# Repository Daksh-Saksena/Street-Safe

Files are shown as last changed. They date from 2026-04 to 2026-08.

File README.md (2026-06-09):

# StreetSafe:
Disaster-response system designed to help people navigate safely during heavy rain and flooding. It improves on traditional GPS by using real-time data to guide users away from unsafe roads. Also the MAIN thing- An autonomous drone that can monitor conditions on the ground, update routes, and assist in search and rescue when situations become bad

So there are 2 parts of our Project, the physical design and drone , and the front end code base:-

___

# DRONE:
We designed the entire custom model including electronics (and 2 custom PCBS) in fusion and kicad, and made a wiring diagram including all the components and the wiring.
## What differentiates us?
Due to our goal of a helpful autonomous weatherproof drone, we had to add multiple unique differentiating parts-

1. Weatherproofing and waterproofing while maintaining airflow to cool components
2. Constant Lidar sensing on top of the drone to autonomously navigate
3. Payload mechanisms which can easilt be swapped out, For a start we have designed two mechanisms already:

* First Aid and small package deliverer - We designed a payload dropper mechanism to drop first aid boxes in times of flooded rains

* WIFI booster - In tree surrounded areas wifi connectivity gets worse exponentially so our drone acts as a network booster such that people can connect to internet and can call in case of emergencies.

___

# CODE:
This codebase is split into two main parts:
1. A Raspberry Pi 5 control system that is designed to run on actual hardware -> WARNING! ! ! -> WE DONT HAVE THE PHSYICAL COMPONENTS YET SO THIS IS LIKE A PLACEHOLDER!
2. A simulation (for testing and demoing) and dashboard system that runs in the browser and backend

Both parts implement the same core idea: an autonomous system that moves toward a goal or keep patrol while continuously avoiding obstacles and adapting to its environment.
1. Raspberry Pi (real-world system)
The pi module contains the code intended to run on a Raspberry Pi connected to a drone.
This part of the code:
* Connects to a flight controller using MAVLink
* Reads data from sensors such as LiDAR and distance sensors
* Processes that data to detect obstacles and measure distances
* Runs a control loop that decides how the drone should move
* Sends movement commandsback to the FC

In each cycle, the system:
1. Reads sensor data
2. Determines if the path ahead is clear
3. Adjusts direction if obstacles are detected
4. Continues moving toward the goal
This is the execution layer that would control a real drone.

2. Simulator + Dashboard (testing system)
The backend and frontend modules together act as a simulation environment.
This 
* Simulates the drone’s position and movement on a map
* Allows obstacles and walls to be placed interactively
* Runs the same navigation logic used on the Pi
* Displays everything visually in real time
It handles
* Routing between locations
* Flood-aware path calculation
* System state updates

The frontend:
* Displays the map (Leaflet)
* Shows the drone, its path, and obstacles
* Updates continuously as the system runs

Key ideas:--
* Move toward a goal or post etc.
* Detect obstacles
* Adjust direction dynamically
* Continue until the destination is reached
The simulator is used for testing and visualisaion (looks v cool) , while the Raspberry Pi code is designed to run the same logic on real hardware or atleast i think it will work .

## How to use:
To run: 
In bash
cd ........./streetsafe
./run_demo.sh

Then open:
http://localhost:9000

This starts the backend and launches dashboard where you can see- drone moving, place obstacles, and test navigation.

___

## Why did we do this? 
where we live-> bangalore gets heavy rains all the time (even in the summer) and its really bad traffic on top of the already infamous bangalore traffic but this can also get quite deadly, so we started this originally as a hackathon project (just some code which is now sitting in Old-website) but then we realised that this could actually be a fun and usefull project and here we are!

Note: Shipping prices are high even on the cheapest project, due to customs while shipping to where we live (India). We have selected the cheapest options.

___

## 3D MODEL
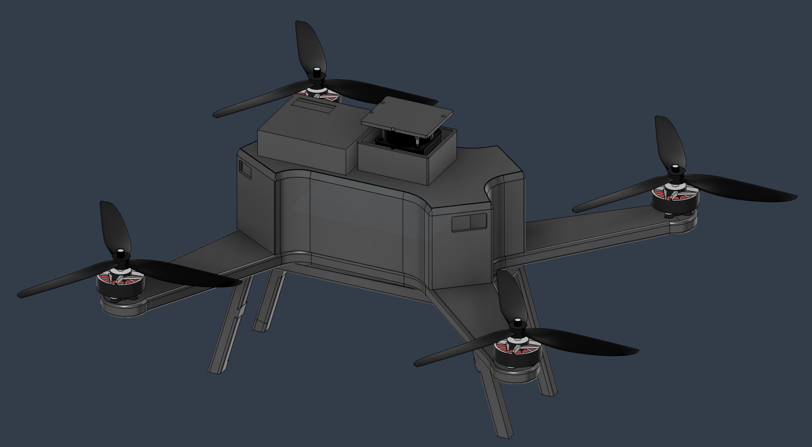
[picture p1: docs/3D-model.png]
3D model


___

## WIRING DIAGRAM
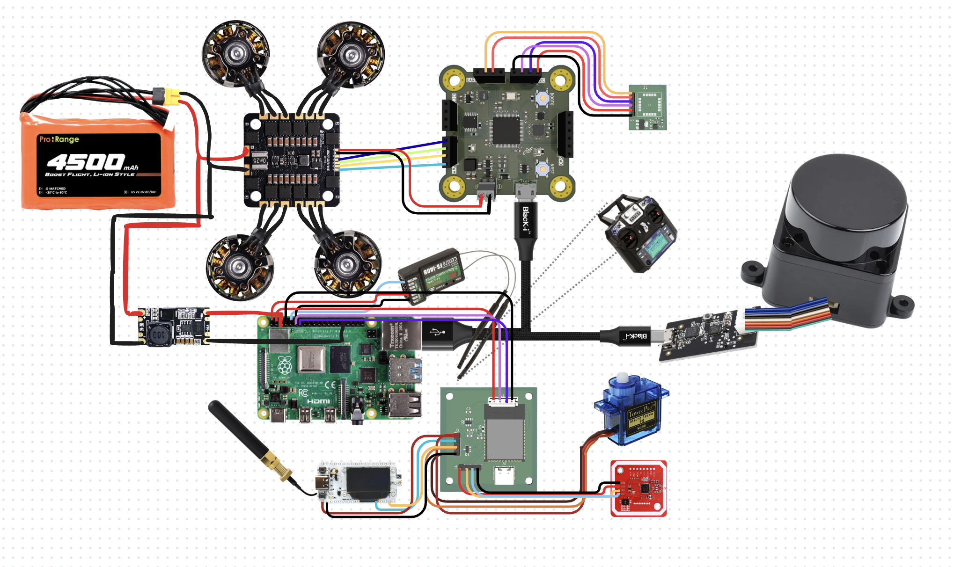
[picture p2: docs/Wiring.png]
Wiring


___

## 3D MODEL OF ELECTRONICS
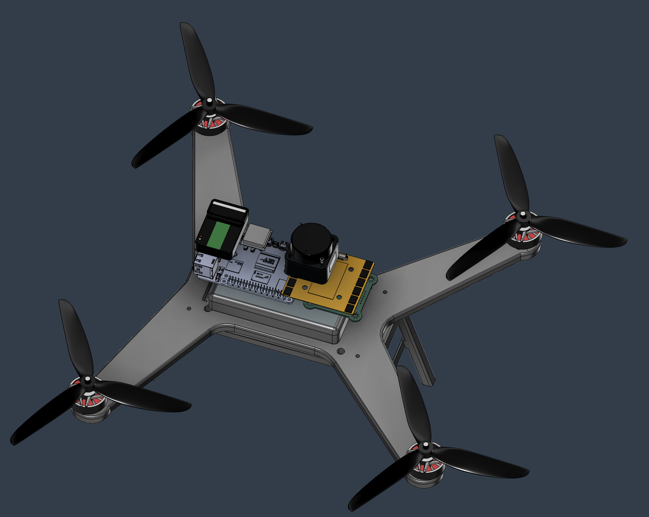
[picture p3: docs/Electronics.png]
Electronic


___

## PAYLOAD 1 - WiFi
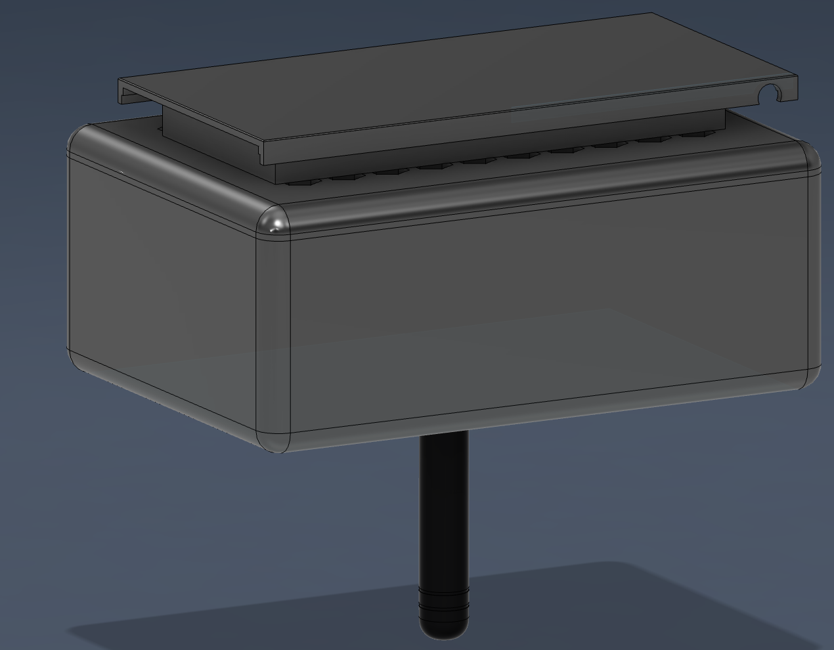
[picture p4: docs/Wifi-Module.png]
Wifi


___

## PAYLOAD 2 - Dropping
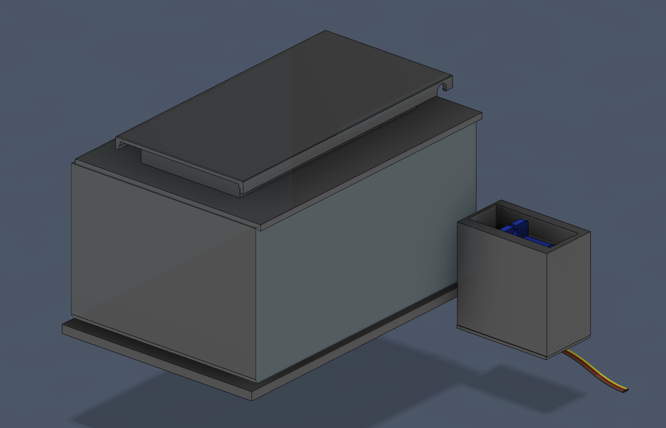
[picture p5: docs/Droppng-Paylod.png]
Dropping payload


___

## PCB 1,2 and 3: FC, GPS and PAYLOAD
<p align="center">
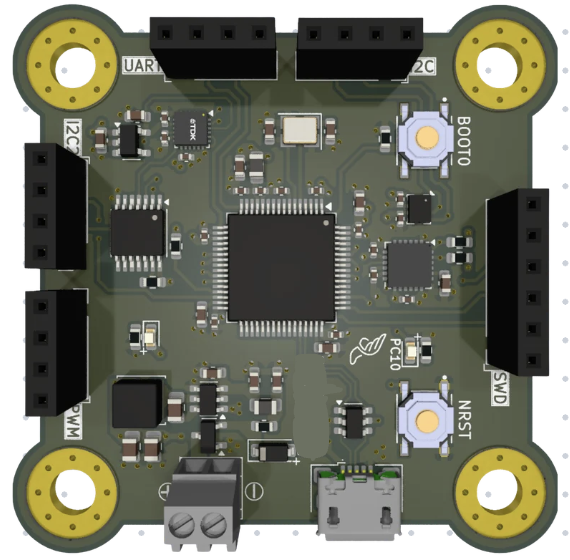
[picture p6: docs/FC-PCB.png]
FC
  
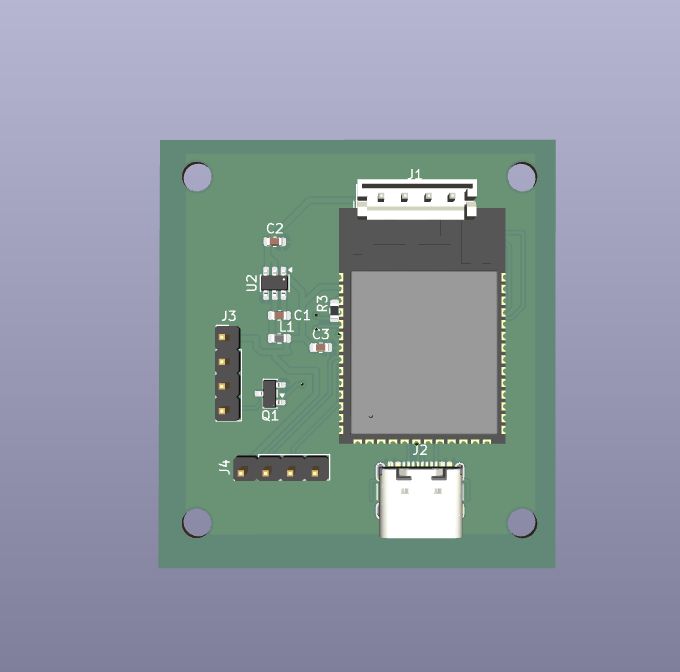
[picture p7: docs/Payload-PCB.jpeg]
PAYLOAD PCB
  
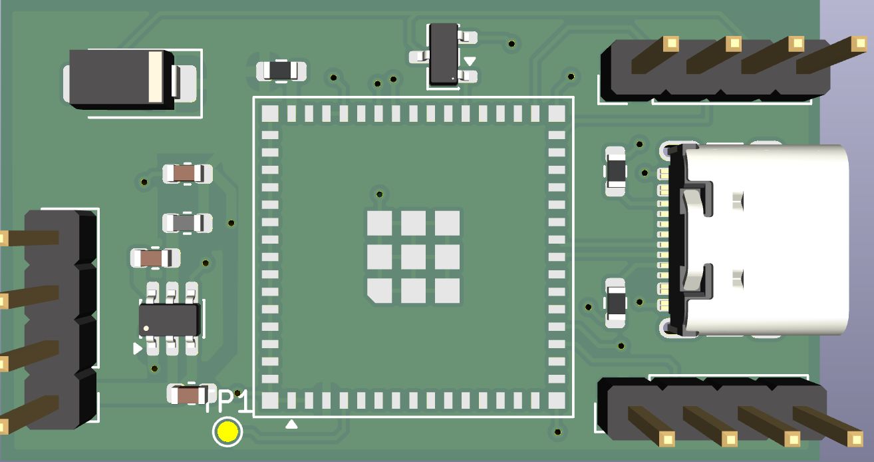
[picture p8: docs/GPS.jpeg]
GPS PCB
  
</p>

___
## Bill of Materials

| Item | Specific Part | Unit Price (INR) | Quantity | Total Price (INR) | URL | Running Total |
| :--- | :--- | :--- | :--- | :--- | :--- | :--- |
| PCB Components | Electronic Components for 3 Custom PCBs | 9,785 | 1 | 9,785 | LCSC, Robu, DigiKey | 9,785 |
| Primary LiDAR | LDROBOT D500 | 7,520 | 1 | 7,520 | [Link](https://robu.in/product/ldrobot-dtof-lidar-stl-19p-360-omni-directional-lidar/) | 17,305 |
| Motors | Emax ECOII 2807 1300KV | 1,700 | 4 | 6,800 | [Link](https://hitechxyz.in/products/emax-ecoii-2807-1300kv-brushless-motor) | 24,105 |
| PCB Manufacturing  | PCB Fabrication (3 Custom PCBs) | 5,890 | 1 | 5,890 | SEEED Fusion | 29,995 |
| Battery | 6S 4500mAh Li-ion | 4,100 | 1 | 4,100 | [Link](https://robu.in/product/pro-range-inr-21700-p45b-22-2v-4500mah-6s1p-35a-45a-discharge-li-ion-drone-battery-pack/) | 34,095 |
| WiFi Module | ESP32 | 1,400 | 1 | 1,400 | [Link](https://robocraze.com/products/wifi-kit-32) | 35,495 |
| Propeller | Gemfan 7040 | 200 | 4 | 800 | [Link](https://hitechxyz.in/products/pro-range-propellers-7040-flash-pc-3-blade-propellers-2cw-2ccw-black) | 36,295 |
| BEC | 13S 5V BEC For Quad | 741 | 1 | 741 | [Link](https://www.flyrobo.in/yrrc-2-13s-5v-5a-bec-module) | 37,036 |
| NFC Tag | PN532 NFC RFID Module | 261 | 1 | 261 | [Link](https://www.flyrobo.in/pn532-nfc-rfid-module-v3-kit) | 37,297 |
| Antenna | 6dBi 2.4GHz 5GHz Dual Band WiFi SMA Antenna | 62 | 1 | 62 | [Link](https://robocraze.com/products/6dbi-2-4ghz-5ghz-dual-band-wifi-rp-sma-antenna-20cm-u-fl-ipex-cable) | 37,359 |
| Companion Computer | Raspberry Pi 5 (4GB) | 0 | 1 | 0 | Already Have | 37,359 |
| Frame | 3D Printed using PETG-CF (cost negligible)  | 0 | 1 | 0 | Cost Negligible | 37,359 |
| Radio | FS-i6 | 0 | 1 | 0 | Already Have | 37,359 |
| ESC | 4-in-1 ESC | 0 | 1 | 0 | Self Funded | 37,359 |
| Servo | SG90 | 0 | 1 | 0 | Already Have | 37,359 |
| Hot Plate | SMD Rework Hot Plate | 0 | 1 | 0 | Macondo Shop | 37,359 |
| Soldering Iron | Soldering Iron Kit | 0 | 1 | 0 | Macondo Shop | 37,359 |
| **Total** | | | | | | **37,359** |

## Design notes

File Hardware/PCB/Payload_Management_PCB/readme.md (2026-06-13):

# Payload Management PCB

This is an esp-32 based management pcb, we made it ourselves in kicad.

---

## Function
This PCB is designed to do 3 things:
* **a) Detect which payload is connected via nfc**
* **b) Provide power to the payload** (has a mosfet to start/stop power when needed)
* **c) Help the PI5:** It basically is designed to offload micro tasks from the pi5, so the pi5 can focus on object avoidance. It handles NFC module identification, manages power routing, and filters raw sensor data before passing clean data to the pi5.

---

## Components
It uses an ESP32 S3 MINI 1U as the microcontroller.  
*See BOM for more clarity.*

---

We added all the production files in the production folder. 

---

## Assembly Instructions
Were using stencils since its our first time working with pcbs. This pcb contains tightly packed components, so we recommend this aswell. Please refer to youtube tutorials aswell.

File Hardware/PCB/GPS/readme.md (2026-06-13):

# GPS PCB

Sooo this is the gps pcb, we made it ourselves in kicad. 

---

## Function
Accurate gps to provide the mission software real time GPS locations to an accuracy of about 1.5m. It also has a compass to tell the software where the drone is pointed.

---

## Components
So the raw GPS module is the uBlox SAM m10q.  
The compass is the IST 8310 module.  
*See bom for more clarity.*

---

We added all the production files in the production folder. I tried to add as many file types as possible so that anyone who needs it can get it easily.

--- 

# Assembly Instructions
1.  **Solder Paste Application:** It is highly recommended to use a laser-cut stainless steel **solder stencil** rather than manual hand-pasting to prevent solder bridging across close-proximity components.
2.  **Component Placement:** Carefully place the surface-mount devices (SMDs), taking extra care with the orientation of the SAM-M10Q patch antenna and the IST8310 alignment dot.
3.  **Reflow Method:** Utilize a temperature-controlled SMD hotplate or reflow oven for assembly. If you are new to hotplate soldering, review proper thermal profiling guidelines to avoid overheating the sensitive internal RF shielding of the GPS receiver.

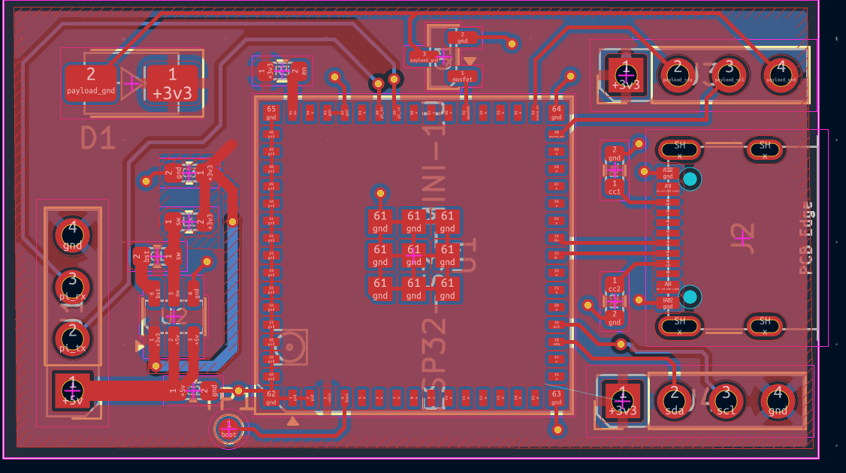
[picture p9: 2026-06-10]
Hardware/PCB/Payload_Management_PCB/pcb.png

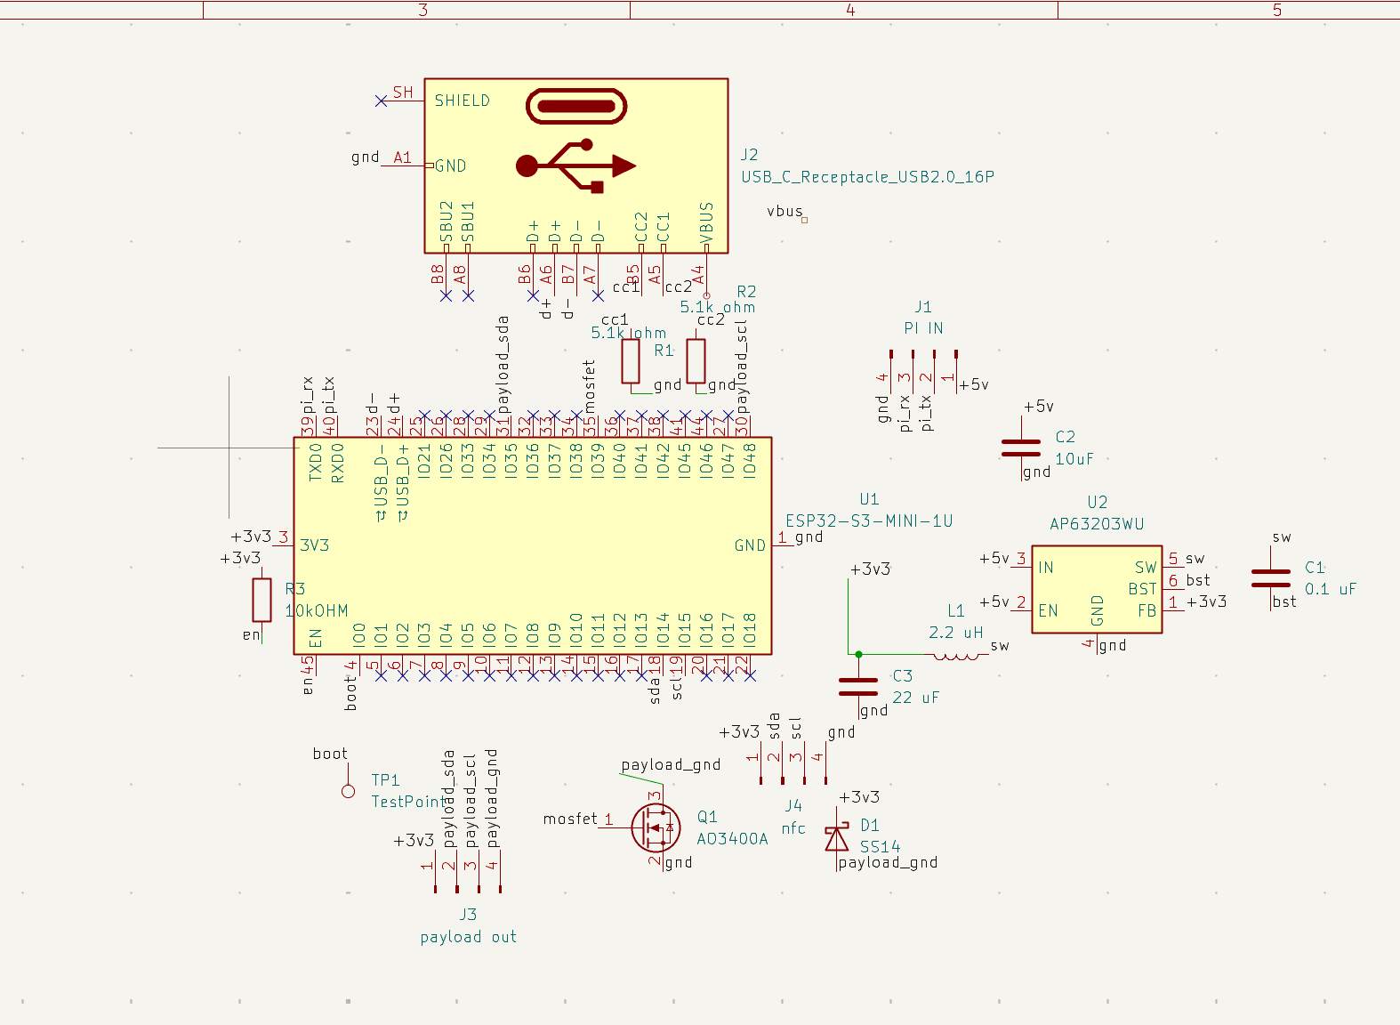
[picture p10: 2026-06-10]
Hardware/PCB/Payload_Management_PCB/schematic.png

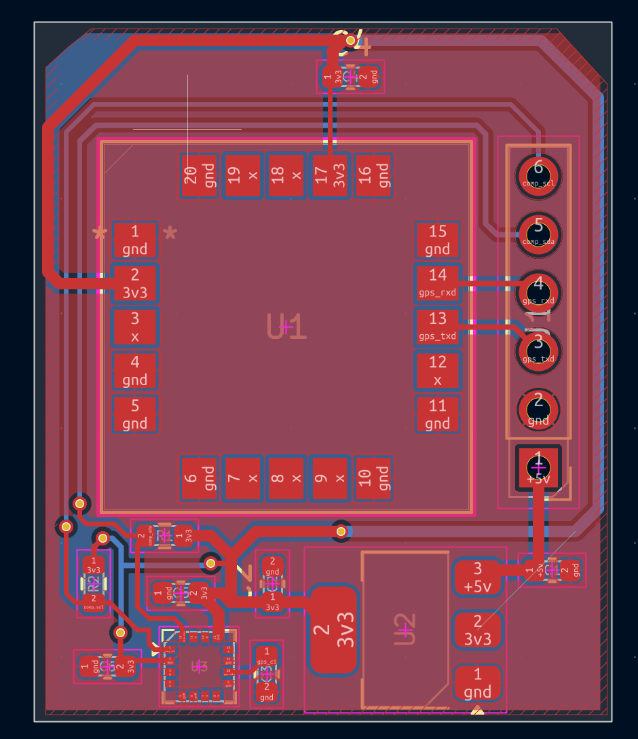
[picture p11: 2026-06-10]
Hardware/PCB/GPS/pcb.png

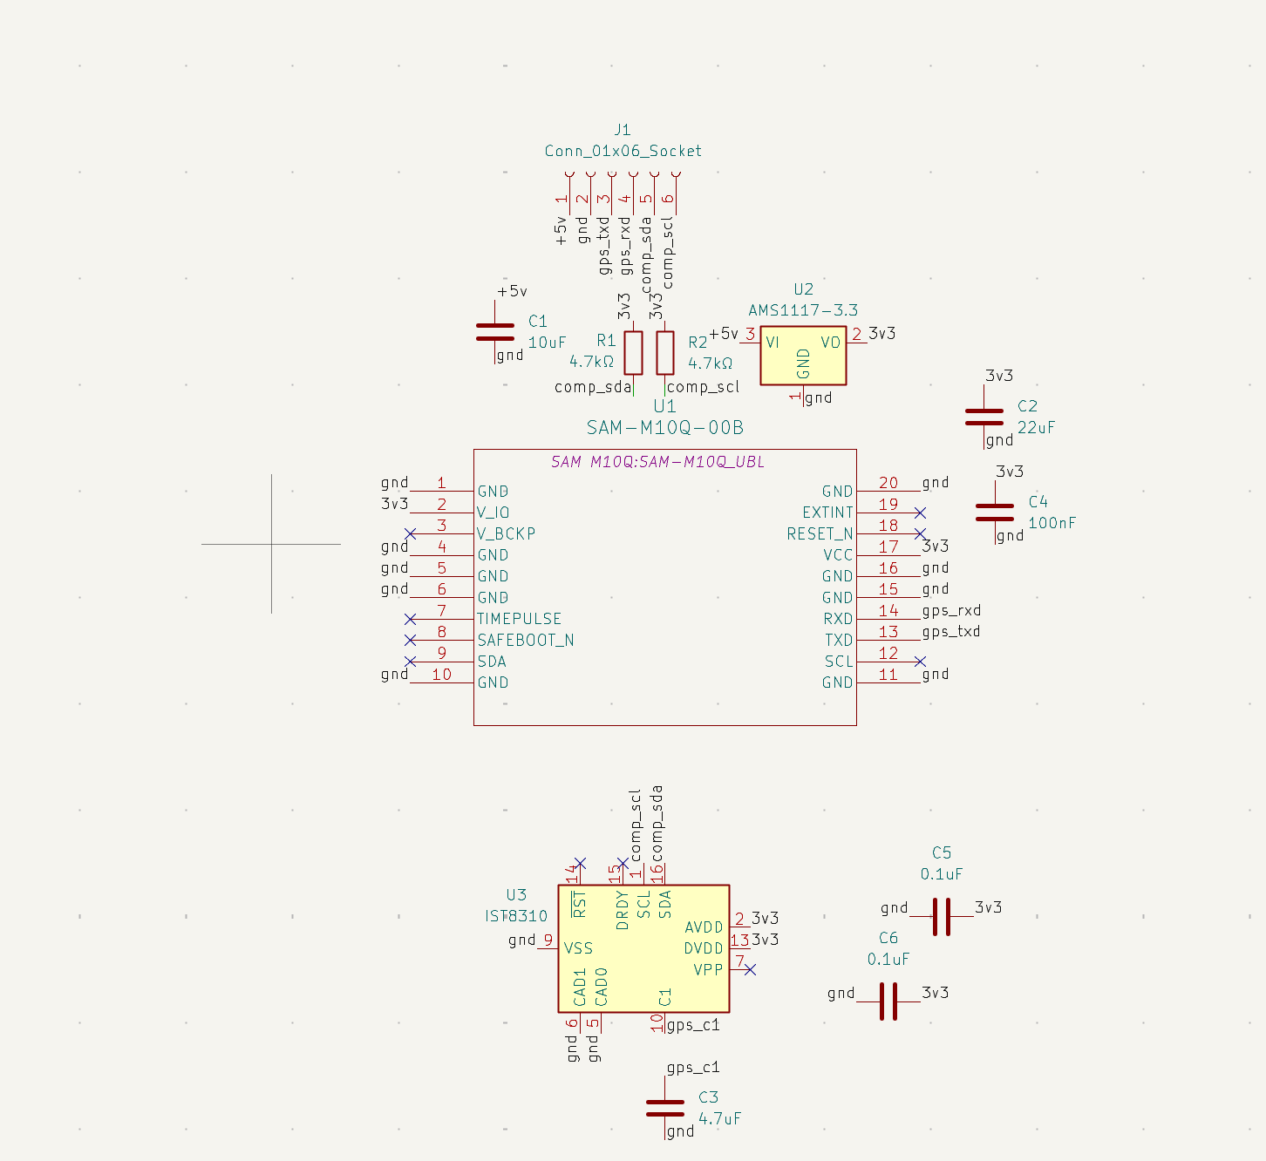
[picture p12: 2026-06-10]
Hardware/PCB/GPS/schematic.png

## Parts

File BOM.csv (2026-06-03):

Item | Specific Part | Unit Price (INR) | Quantity | Total Price (INR) | URL / Source | Running Total (INR)
PCB Components | Electronic Components for 3 Custom PCBs | 9785 | 1 | 9785 | LCSC, Robu, DigiKey | 9785
Primary LiDAR | LDROBOT D500 | 7520 | 1 | 7520 | https://robu.in/product/ldrobot-dtof-lidar-stl-19p-360-omni-directional-lidar/ | 17305
Motors | Emax ECOII 2807 1300KV | 1700 | 4 | 6800 | https://hitechxyz.in/products/emax-ecoii-2807-1300kv-brushless-motor | 24105
PCB Manufacturing | PCB Fabrication (3 Custom PCBs) | 5890 | 1 | 5890 | SEEED Fusion | 29995
Battery | 6S 4500mAh Li-ion | 4100 | 1 | 4100 | https://robu.in/product/pro-range-inr-21700-p45b-22-2v-4500mah-6s1p-35a-45a-discharge-li-ion-drone-battery-pack/ | 34095
WiFi Module | ESP32 | 1400 | 1 | 1400 | https://robocraze.com/products/wifi-kit-32 | 35495
Propeller | Gemfan 7040 | 200 | 4 | 800 | https://hitechxyz.in/products/pro-range-propellers-7040-flash-pc-3-blade-propellers-2cw-2ccw-black | 36295
BEC | 13S 5V BEC For Quad | 741 | 1 | 741 | https://www.flyrobo.in/yrrc-2-13s-5v-5a-bec-module | 37036
NFC Tag | PN532 NFC RFID Module | 261 | 1 | 261 | https://www.flyrobo.in/pn532-nfc-rfid-module-v3-kit | 37297
Antenna | 6dBi Dual Band WiFi SMA Antenna | 62 | 1 | 62 | https://robocraze.com/products/6dbi-2-4ghz-5ghz-dual-band-wifi-rp-sma-antenna-20cm-u-fl-ipex-cable | 37359
Companion Computer | Raspberry Pi 5 (4GB) - Already Have | 0 | 1 | 0 | Already Have | 37359
Frame | 3D Printed PETG-CF - Cost Negligible | 0 | 1 | 0 | Cost Negligible | 37359
Radio | FS-i6 - Already Have | 0 | 1 | 0 | Already Have | 37359
ESC | 4-in-1 ESC - Self Funded | 0 | 1 | 0 | Self Funded | 37359
Servo | SG90 - Already Have | 0 | 1 | 0 | Already Have | 37359
Hot Plate | SMD Rework Hot Plate | 0 | 1 | 0 | Macondo Shop | 37359
Soldering Iron | Soldering Iron Kit | 0 | 1 | 0 | Macondo Shop | 37359
Total |  |  |  | 37359

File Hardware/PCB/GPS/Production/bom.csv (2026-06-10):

Id | Designator | Footprint | Quantity | Designation | Supplier and ref
1 | C1 | C_0603_1608Metric | 1 | 10uF
2 | C2 | C_0603_1608Metric | 1 | 22uF
3 | C3 | C_0603_1608Metric | 1 | 4.7uF
4 | C4 | C_0603_1608Metric | 1 | 100nF
5 | C5, C6 | C_0603_1608Metric | 2 | 0.1uF
6 | J1 | PinHeader_1x06_P2.54mm_Vertical | 1 | Conn_01x06_Socket
7 | R1, R2 | R_0603_1608Metric | 2 | 4.7kΩ
8 | U1 | SAM-M10Q_UBL | 1 | SAM-M10Q-00B
9 | U2 | SOT-223-3_TabPin2 | 1 | AMS1117-3.3
10 | U3 | LGA-16_3x3mm_P0.5mm | 1 | IST8310

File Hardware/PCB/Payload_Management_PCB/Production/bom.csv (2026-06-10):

Id | Designator | Footprint | Quantity | Designation | Supplier and ref
1 | C1 | C_0603_1608Metric | 1 | 0.1 uF
2 | C2 | C_0603_1608Metric | 1 | 10uF
3 | C3 | C_0603_1608Metric | 1 | 22 uF
4 | D1 | D_SMA | 1 | SS14
5 | J1 | PinHeader_1x04_P2.54mm_Vertical | 1 | PI IN
6 | J2 | USB_C_Receptacle_GCT_USB4105-xx-A_16P_TopMnt_Horizontal | 1 | USB_C_Receptacle_USB2.0_16P
7 | J3 | PinHeader_1x04_P2.54mm_Vertical | 1 | payload out
8 | J4 | PinHeader_1x04_P2.54mm_Vertical | 1 | nfc
9 | L1 | L_0603_1608Metric | 1 | 2.2 uH
10 | Q1 | SOT-23 | 1 | AO3400A
11 | R1, R2 | R_0603_1608Metric | 2 | 5.1k ohm
12 | R3 | R_0603_1608Metric | 1 | 10kOHM
13 | TP1 | TestPoint_Pad_D1.0mm | 1 | TestPoint
14 | U1 | ESP32-S2-MINI-1U | 1 | ESP32-S3-MINI-1U
15 | U2 | TSOT-23-6 | 1 | AP63203WU

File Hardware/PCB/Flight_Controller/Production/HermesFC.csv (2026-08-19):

Id | Designator | Footprint | Quantity | Designation | Supplier and ref
1 | C1, C9, C17, C28, C29 | C_0603_1608Metric | 5 | 10u
2 | C2, C3, C4, C5, C6, C7, C8, C10, C21, C22, C23, C25, C26, C27, C30, C31 | C_0402_1005Metric | 16 | 100n
3 | C11, C12 | C_0603_1608Metric | 2 | 10p
4 | C13, C14, C15, C16 | C_0603_1608Metric | 4 | 2u2
5 | C18 | C_0805_2012Metric | 1 | 100n
6 | C19, C20 | C_0805_2012Metric | 2 | 22u
7 | C24 | C_0603_1608Metric | 1 | 2n2
8 | D1, D3 | LED_0603_1608Metric | 2 | LED
9 | D2 | D_SOD-123 | 1 | b5819w
10 | F1 | Fuse_0603_1608Metric | 1 | 500 mA
11 | FB1, FB2 | L_0805_2012Metric | 2 | 100R
12 | J1, J3, J4, J5 | PinSocket_1x04_P2.54mm_Vertical | 4 | Conn_01x04
13 | J2 | TerminalBlock_Xinya_XY308-2.54-2P_1x02_P2.54mm_Horizontal | 1 | Screw_Terminal_01x02
14 | J6 | PinSocket_1x06_P2.54mm_Vertical | 1 | Conn_01x06
15 | J7 | USB_Micro-B_Amphenol_10118193-0001LF_Horizontal | 1 | USB_B_Micro
16 | L1 | L_Taiyo-Yuden_MD-5050 | 1 | 3.9uH
17 | Q1 | SOT-23 | 1 | AO3401A
18 | R1 | R_0603_1608Metric | 1 | 10k
19 | R2, R3, R5, R6 | R_0603_1608Metric | 4 | 2k2
20 | R4, R7 | R_0603_1608Metric | 2 | 1k
21 | S1, S2 | SW_TS-1187A-B-A-B | 2 | TS-1187A-B-A-B
22 | U1 | LQFP-64_10x10mm_P0.5mm | 1 | STM32F405RGTx
23 | U2 | TSOT-23-6 | 1 | AP63203WU
24 | U3 | SOT-23-6 | 1 | USBLC6-2SC6
25 | U4 | InvenSense_QFN-24_4x4mm_P0.5mm | 1 | MPU-6050
26 | U5 | InvenSense_QFN-24_3x3mm_P0.4mm | 1 | ICM-20948
27 | U6 | SOT-23-5 | 1 | LD39015M18R
28 | U7 | TSSOP-14_4.4x5mm_P0.65mm | 1 | NTS0104PW
29 | U9 | QFN10_BMP581_BOS | 1 | BMP581
30 | Y1 | Crystal_SMD_3225-4Pin_3.2x2.5mm | 1 | 16Mhz

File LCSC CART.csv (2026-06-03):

Index | LCSC# | MPN | Manufacturer | Package | Customer # | Description | RoHS | Quantity | MOQ | Multiple | Unit Price($) | Extended Price($) | Product Link
1 | C22548 | RC0603FR-071KL | YAGEO | 0603 |  | 100mW 1kΩ 75V Thick Film Resistor ±100ppm/℃ ±1% 0603 Chip Resistor - Surface Mount RoHS | yes | 100 | 100 | 100 | 0.0016 | 0.16 | https://www.lcsc.com/product-detail/C22548.html
2 | C95204 | RT0603BRD0710KL | YAGEO | 0603 |  | 100mW 10kΩ 75V Thin Film Resistor ±25ppm/℃ ±0.1% 0603 Chip Resistor - Surface Mount RoHS | yes | 20 | 20 | 20 | 0.0232 | 0.46 | https://www.lcsc.com/product-detail/C95204.html
3 | C19702 | CL10A106KP8NNNC | Samsung Electro-Mechanics | 0603 |  | 10uF ±10% 10V Ceramic Capacitor X5R 0603 | yes | 20 | 20 | 20 | 0.0139 | 0.28 | https://www.lcsc.com/product-detail/C19702.html
4 | C86295 | CL10A226MP8NUNE | Samsung Electro-Mechanics | 0603 |  | 22uF ±20% 10V Ceramic Capacitor X5R 0603 | yes | 10 | 10 | 10 | 0.0211 | 0.21 | https://www.lcsc.com/product-detail/C86295.html
5 | C19666 | CL10A475KO8NNNC | Samsung Electro-Mechanics | 0603 |  | 4.7uF ±10% 16V Ceramic Capacitor X5R 0603 | yes | 10 | 10 | 10 | 0.0140 | 0.14 | https://www.lcsc.com/product-detail/C19666.html
6 | C1590 | CL10B104KA8NNNC | Samsung Electro-Mechanics | 0603 |  | 100nF ±10% 25V Ceramic Capacitor X7R 0603 | yes | 100 | 100 | 100 | 0.0049 | 0.49 | https://www.lcsc.com/product-detail/C1590.html
7 | C3715625 | 69146-206LF | Amphenol | P=2.54mm |  | Open-Top 2.54mm P=2.54mm Shunts, Jumpers RoHS | yes | 1 | 1 | 1 | 1.0735 | 1.07 | https://www.lcsc.com/product-detail/C3715625.html
8 | C99782 | RC0603FR-074K7L | YAGEO | 0603 |  | 100mW 4.7kΩ 75V Thick Film Resistor ±100ppm/℃ ±1% 0603 Chip Resistor - Surface Mount RoHS | yes | 100 | 100 | 100 | 0.0015 | 0.15 | https://www.lcsc.com/product-detail/C99782.html
9 | C6186 | AMS1117-3.3 | Advanced Monolithic Systems | SOT-223 |  | 3.3V Positive Fixed SOT-223 Voltage Regulators - Linear, Low Drop Out (LDO) Regulators RoHS | yes | 5 | 5 | 5 | 0.2036 | 1.02 | https://www.lcsc.com/product-detail/C6186.html
10 | C2683055 | IST8310 | iSentek | LGA-16(3x3) |  | LGA-16(3x3) Linear, Compass (ICs) | - | 1 | 1 | 1 | 5.6313 | 5.63 | https://www.lcsc.com/product-detail/C2683055.html
11 | C96446 | CL10A106MA8NRNC | Samsung Electro-Mechanics | 0603 |  | 10uF ±20% 25V Ceramic Capacitor X5R 0603 | yes | 20 | 20 | 20 | 0.0307 | 0.61 | https://www.lcsc.com/product-detail/C96446.html
12 | C1525 | CL05B104KO5NNNC | Samsung Electro-Mechanics | 0402 |  | 100nF ±10% 16V Ceramic Capacitor X7R 0402 | yes | 100 | 100 | 100 | 0.0017 | 0.17 | https://www.lcsc.com/product-detail/C1525.html
13 | C1634 | CL10C100JB8NNNC | Samsung Electro-Mechanics | 0603 |  | 10pF ±5% 50V Ceramic Capacitor C0G 0603 | yes | 100 | 100 | 100 | 0.0057 | 0.57 | https://www.lcsc.com/product-detail/C1634.html
14 | C23630 | CL10A225KO8NNNC | Samsung Electro-Mechanics | 0603 |  | 2.2uF ±10% 16V Ceramic Capacitor X5R 0603 | yes | 50 | 50 | 50 | 0.0093 | 0.47 | https://www.lcsc.com/product-detail/C23630.html
15 | C49678 | CC0805KRX7R9BB104 | YAGEO | 0805 |  | 100nF ±10% 50V Ceramic Capacitor X7R 0805 | yes | 100 | 100 | 100 | 0.0078 | 0.78 | https://www.lcsc.com/product-detail/C49678.html
16 | C45783 | CL21A226MAQNNNE | Samsung Electro-Mechanics | 0805 |  | 22uF ±20% 25V Ceramic Capacitor X5R 0805 | yes | 20 | 20 | 20 | 0.0632 | 1.26 | https://www.lcsc.com/product-detail/C45783.html
17 | C1604 | 0603B222K500NT | FH | 0603 |  | 2.2nF ±10% 50V Ceramic Capacitor X7R 0603 | yes | 100 | 100 | 100 | 0.0038 | 0.38 | https://www.lcsc.com/product-detail/C1604.html
18 | C2286 | KT-0603R | Hubei KENTO Elec | 0603 |  | Red 645nm LED Indication - Discrete 2.4V 0603 | yes | 100 | 100 | 100 | 0.0070 | 0.70 | https://www.lcsc.com/product-detail/C2286.html
19 | C8598 | B5819W SL | JSCJ | SOD-123 |  | Diode 40V 1A Surface Mount SOD-123 | yes | 20 | 20 | 20 | 0.0244 | 0.49 | https://www.lcsc.com/product-detail/C8598.html
20 | C20798 | SMD1206P025TF | RUILON | 1206 |  | Polymeric PTC Resettable Fuse 16V 250mA Surface Mount 1206 | yes | 10 | 10 | 10 | 0.0873 | 0.87 | https://www.lcsc.com/product-detail/C20798.html
21 | C17408 | 0805W8F1000T5E | UNI-ROYAL | 0805 |  | 100Ω ±1% 125mW 0805 Thick Film Resistor | yes | 100 | 100 | 100 | 0.0024 | 0.24 | https://www.lcsc.com/product-detail/C17408.html
22 | C167872 | FNR4030S3R9MT | cjiang | SMD,4x4mm |  | 2.3A 3.9uH ±20% 3.3A 74mΩ Magnetic Shielded Inductor SMD,4x4mm Fixed Inductors RoHS | yes | 10 | 10 | 10 | 0.0791 | 0.79 | https://www.lcsc.com/product-detail/C167872.html
23 | C15127 | AO3401A | AOS | SOT-23 |  | 30V 4A Surface Mount SOT-23 | yes | 10 | 10 | 10 | 0.0629 | 0.63 | https://www.lcsc.com/product-detail/C15127.html
24 | C25804 | 0603WAF1002T5E | UNI-ROYAL | 0603 |  | 10kΩ ±1% 100mW 0603 Thick Film Resistor | yes | 200 | 100 | 100 | 0.0033 | 0.66 | https://www.lcsc.com/product-detail/C25804.html
25 | C4190 | 0603WAF2201T5E | UNI-ROYAL | 0603 |  | 2.2kΩ ±1% 100mW 0603 Thick Film Resistor | yes | 100 | 100 | 100 | 0.0015 | 0.15 | https://www.lcsc.com/product-detail/C4190.html
26 | C21190 | 0603WAF1001T5E | UNI-ROYAL | 0603 |  | 1kΩ ±1% 100mW 0603 Thick Film Resistor | yes | 100 | 100 | 100 | 0.0016 | 0.16 | https://www.lcsc.com/product-detail/C21190.html
27 | C318884 | TS-1187A-B-A-B | XKB Connection | SMD-4P,5.1x5.1mm |  | Tactile Switch SPST 160gf 1.5mm 5.1mm x 5.1mm Surface Mount | yes | 20 | 20 | 20 | 0.0206 | 0.41 | https://www.lcsc.com/product-detail/C318884.html
28 | C15742 | STM32F405RGT6 | ST | LQFP-64(10x10) |  | ARM Cortex-M4 32 Bit 168MHz 51 LQFP-64(10x10) Microcontrollers RoHS | yes | 2 | 1 | 1 | 4.2933 | 8.59 | https://www.lcsc.com/product-detail/C15742.html
29 | C780769 | AP63203WU-7 | DIODES | TSOT-23-6 |  | 1.1MHz Step-down type Fixed 2A 3.3V TSOT-23-6 Voltage Regulators - DC DC Switching Regulators RoHS | yes | 2 | 1 | 1 | 0.5593 | 1.12 | https://www.lcsc.com/product-detail/C780769.html
30 | C7519 | USBLC6-2SC6 | ST | SOT-23-6L |  | 17VC Clamp 5A Ipp ESD DIODE SOT-23-6L | yes | 5 | 5 | 5 | 0.1531 | 0.77 | https://www.lcsc.com/product-detail/C7519.html
31 | C361025 | LD39015M18R | ST | SOT-23-5 |  | 1.8V Positive Fixed SOT-23-5 Voltage Regulators - Linear, Low Drop Out (LDO) Regulators RoHS | yes | 1 | 1 | 1 | 0.7042 | 0.70 | https://www.lcsc.com/product-detail/C361025.html
32 | C2802637 | NTS0104PW,118 | NXP | TSSOP-14 |  | 50Mbps 1 4 TSSOP-14 Translators, Level Shifters RoHS | yes | 1 | 1 | 1 | 0.9592 | 0.96 | https://www.lcsc.com/product-detail/C2802637.html
33 | C83291 | BMP280 | Bosch | LGA-8(2x2.5) |  | 30Kpa~1.1bar LGA-8(2x2.5) Pressure Sensors, Transducers RoHS | yes | 1 | 1 | 1 | 6.8962 | 6.90 | https://www.lcsc.com/product-detail/C83291.html
34 | C13738 | X322516MLB4SI | YXC Crystal Oscillators | SMD3225-4P |  | Crystal 16MHz ±10ppm 9pF SMD3225-4P | yes | 10 | 10 | 10 | 0.0723 | 0.72 | https://www.lcsc.com/product-detail/C13738.html
35 | C14663 | CC0603KRX7R9BB104 | YAGEO | 0603 |  | 100nF ±10% 50V Ceramic Capacitor X7R 0603 | yes | 100 | 100 | 100 | 0.0075 | 0.75 | https://www.lcsc.com/product-detail/C14663.html
36 | C159801 | CL10A226MQ8NRNE | Samsung Electro-Mechanics | 0603 |  | 22uF ±20% 6.3V Ceramic Capacitor X5R 0603 | yes | 20 | 20 | 20 | 0.0135 | 0.27 | https://www.lcsc.com/product-detail/C159801.html
37 | C2480 | SS14 | MDD(Microdiode Semiconductor) | SMA(DO-214AC) |  | Diode Independent 40V 1A Surface Mount SMA(DO-214AC) | yes | 50 | 50 | 50 | 0.0169 | 0.85 | https://www.lcsc.com/product-detail/C2480.html
38 | C20917 | AO3400A | AOS | SOT-23 |  | N-Channel 30V Surface Mount SOT-23-3L | yes | 5 | 5 | 5 | 0.0828 | 0.41 | https://www.lcsc.com/product-detail/C20917.html
39 | C23186 | 0603WAF5101T5E | UNI-ROYAL | 0603 |  | 5.1kΩ ±1% 100mW 0603 Thick Film Resistor | yes | 100 | 100 | 100 | 0.0016 | 0.16 | https://www.lcsc.com/product-detail/C23186.html
40 | C2980299 | ESP32-S3-MINI-1U-N8 | ESPRESSIF | VFQFN-56-EP |  | 2.4GHz ESP32-S3 -98.4dBm VFQFN-56-EP RF Transceiver Modules and Modems RoHS | yes | 1 | 1 | 1 | 4.9065 | 4.91 | https://www.lcsc.com/product-detail/C2980299.html

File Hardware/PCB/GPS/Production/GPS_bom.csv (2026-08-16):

Id | Designator | Footprint | Quantity | Designation | Supplier and ref
1 | C1 | C_0603_1608Metric | 1 | 10uF
2 | C2 | C_0603_1608Metric | 1 | 22uF
3 | C4 | C_0603_1608Metric | 1 | 100nF
4 | C7 | C_0603_1608Metric | 1 | 10uf
5 | C8 | C_0603_1608Metric | 1 | 1 uf
6 | J1 | PinHeader_1x06_P2.54mm_Vertical | 1 | Conn_01x06_Socket
7 | R1, R2 | R_0603_1608Metric | 2 | 4.7kΩ
8 | U1 | SAM-M10Q_UBL | 1 | SAM-M10Q-00B
9 | U2 | SOT-223-3_TabPin2 | 1 | AMS1117-3.3
10 | U4 | MMC5983MA_MEM | 1 | MMC5983MA

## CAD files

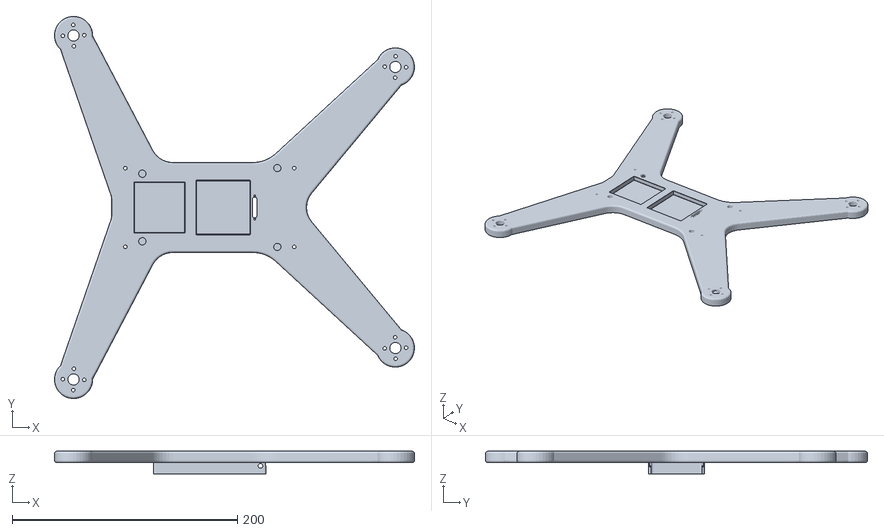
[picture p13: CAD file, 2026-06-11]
Hardware/3D Printed/Main frame.stl
319.8 x 339.5 x 20.0

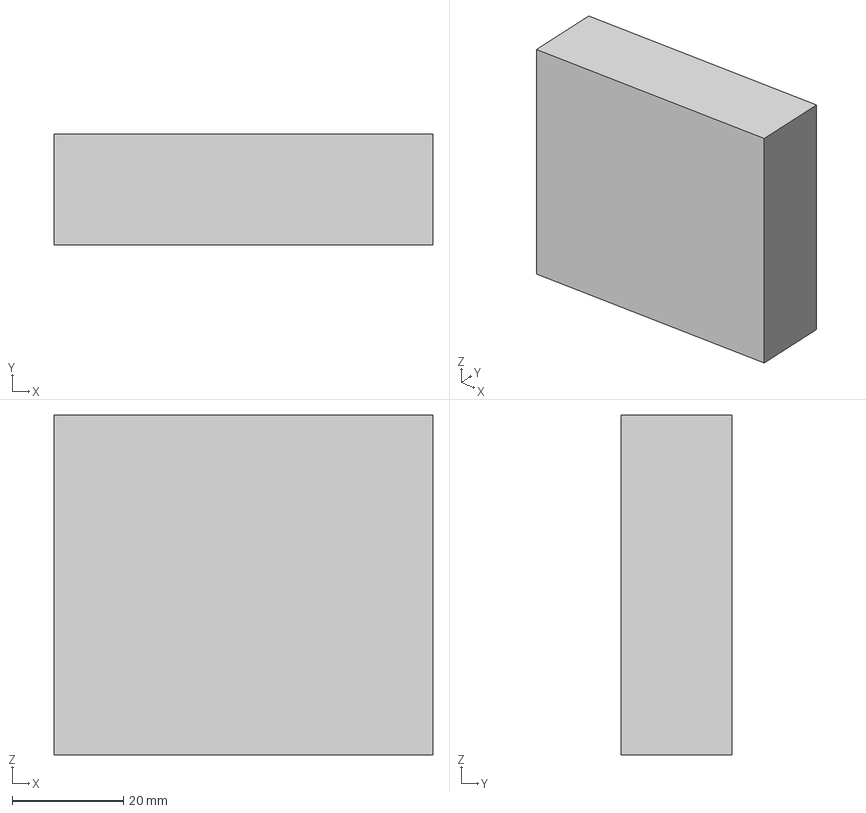
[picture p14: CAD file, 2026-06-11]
Hardware/step/esc+holder.stp
68.0 x 20.0 x 61.0 mm

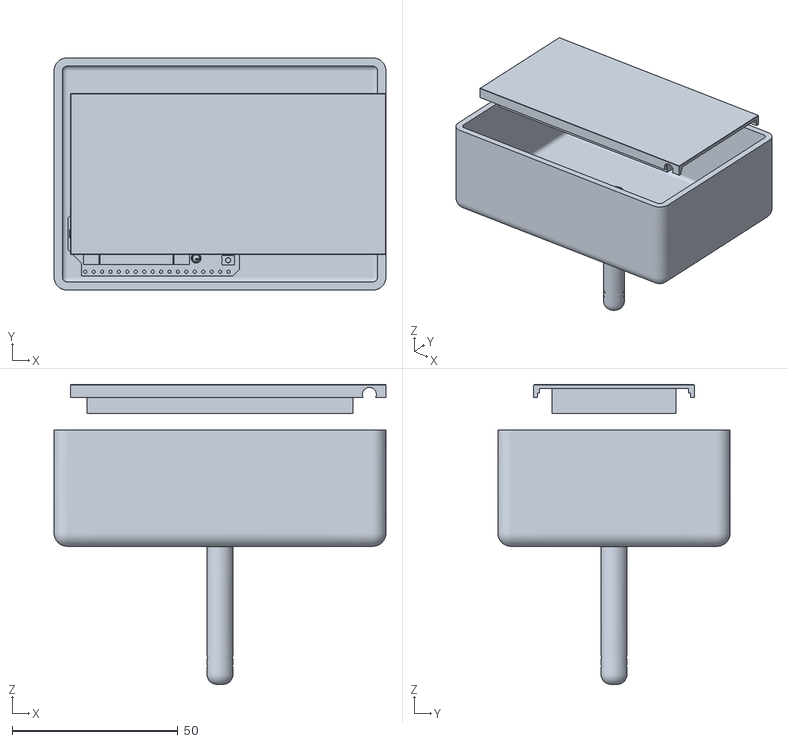
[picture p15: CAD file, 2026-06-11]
Hardware/3D Printed/Wifi payload.stl
100.0 x 70.0 x 90.4

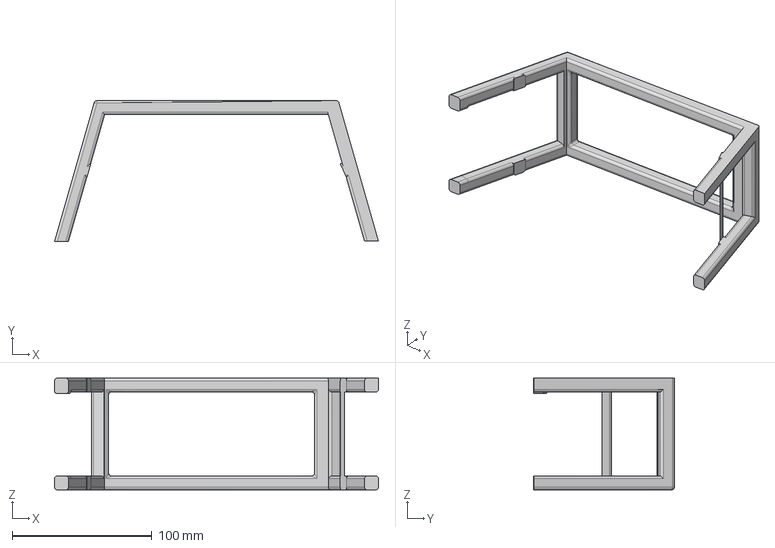
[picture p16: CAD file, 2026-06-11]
Hardware/step/Stand.stp
231.8 x 100.7 x 80.0 mm

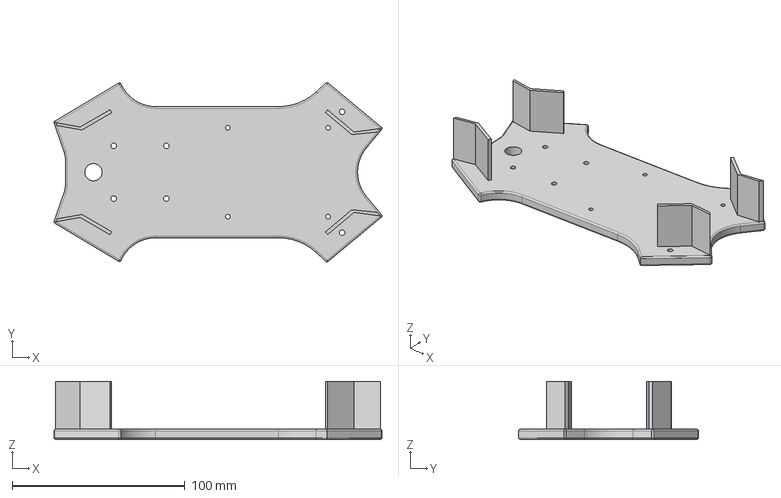
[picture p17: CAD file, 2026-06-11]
Hardware/step/Electronics+shelf.stp
189.9 x 104.1 x 33.6 mm

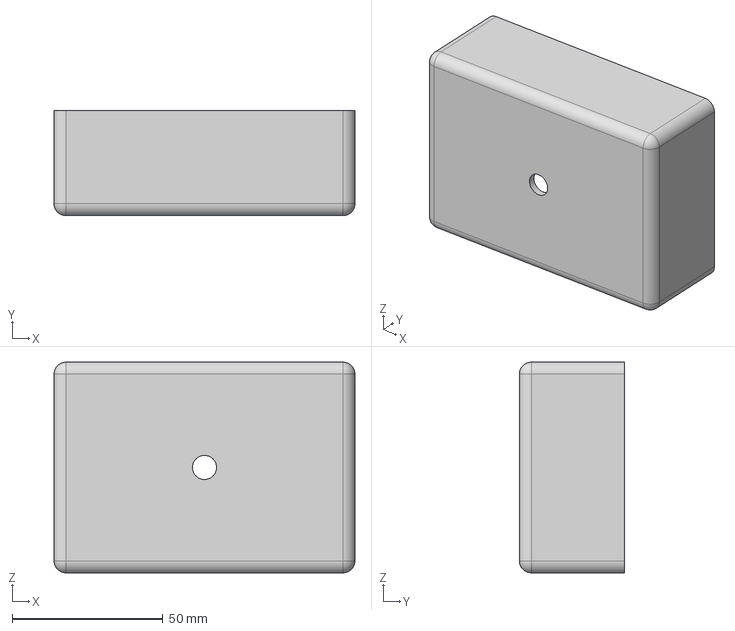
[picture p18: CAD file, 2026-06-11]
Hardware/step/wifi+connectivity.stp
100.0 x 35.0 x 70.0 mm

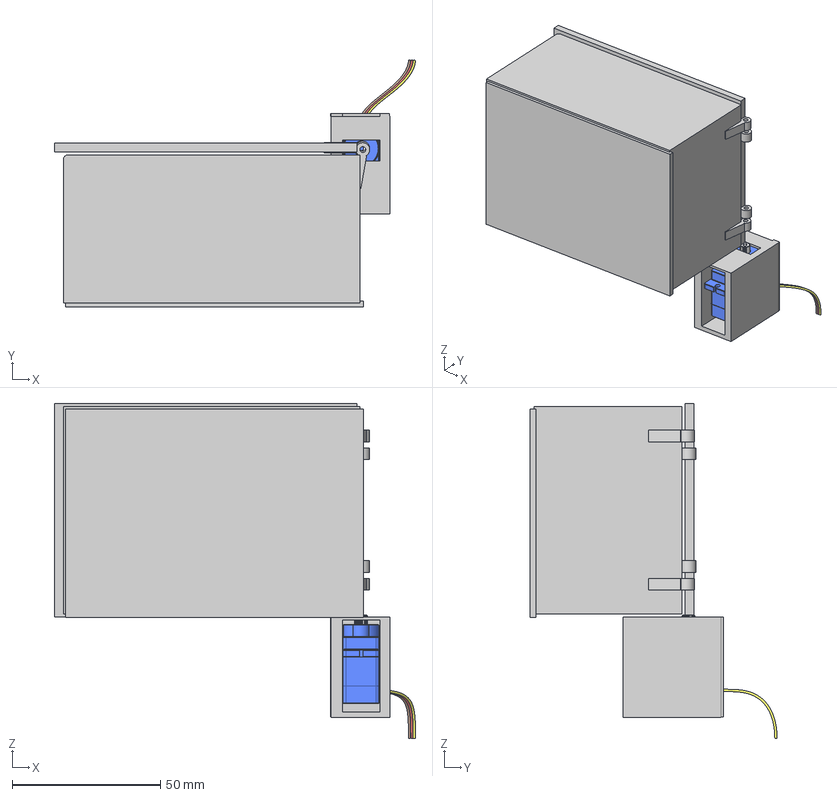
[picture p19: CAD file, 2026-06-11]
Hardware/step/carrier+payload.stp
121.7 x 83.4 x 113.1 mm
Servo_1
PernoServo

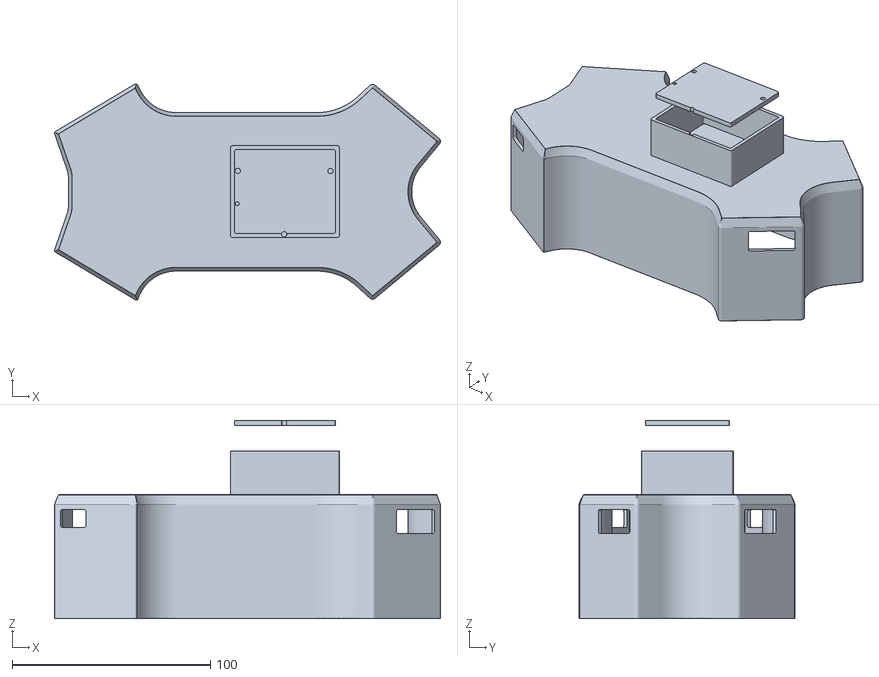
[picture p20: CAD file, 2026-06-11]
Hardware/3D Printed/Water+Resistent+cover.stl
194.7 x 109.1 x 100.0

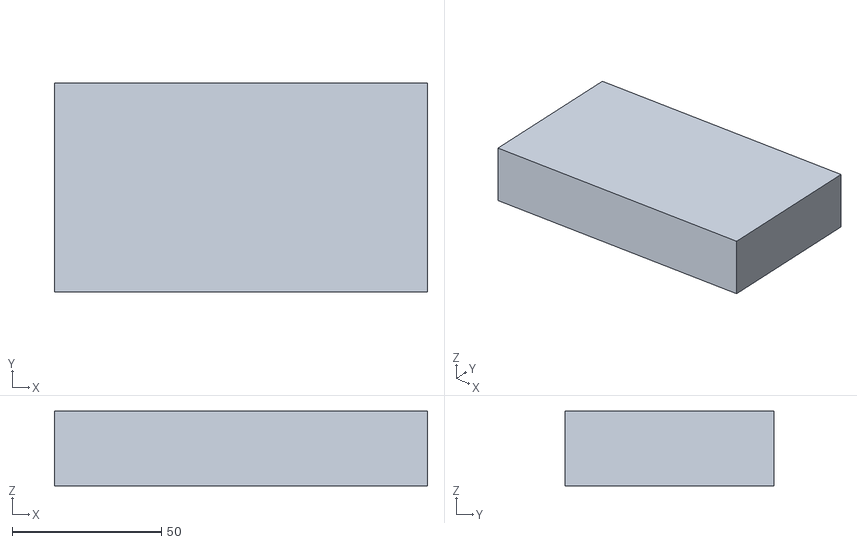
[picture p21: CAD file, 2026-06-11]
Hardware/3D Printed/Battery+holder.stl
125.0 x 70.0 x 25.0

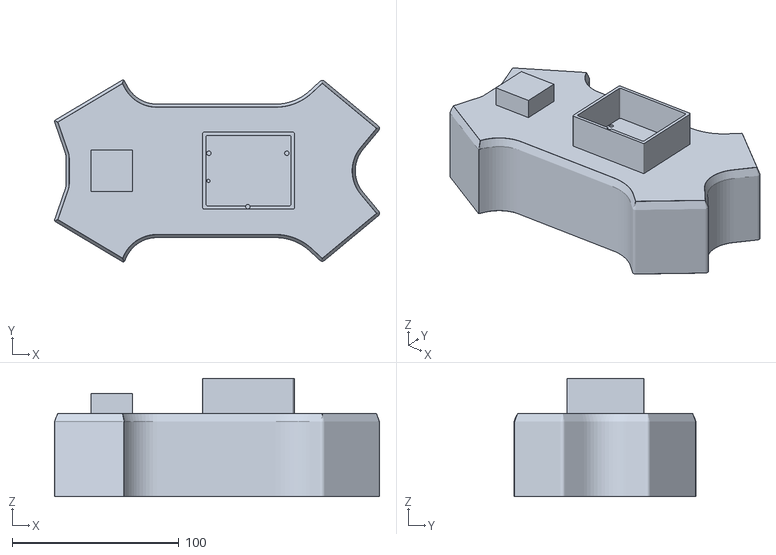
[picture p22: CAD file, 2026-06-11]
Hardware/3D Printed/Cooling+system.stl
194.7 x 109.1 x 71.0

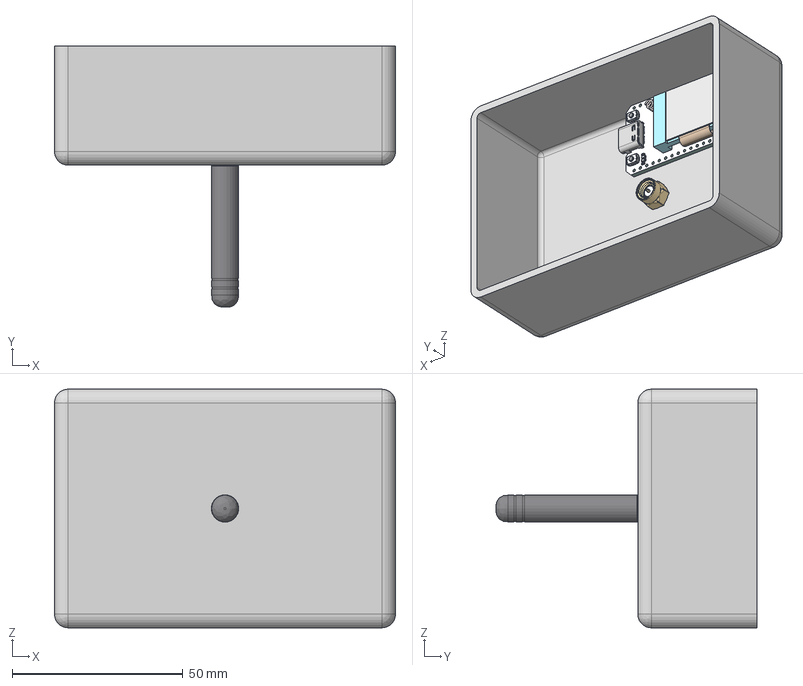
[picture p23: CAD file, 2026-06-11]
Hardware/step/wifi+payload.stp
100.0 x 76.6 x 70.0 mm
board
screen_frame
90380A322_Phillips Rounded Head Thread-Forming Screws x 3
cover x 2
conn001 x 2
conn002 x 2
cap x 2
0402 Resistor x 2
0603 Chip SMD LED (1.6x0.8mm) x 2
IPEX U.FL-R-SMT
antenna_1
power socket
screen

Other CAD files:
Hardware/step/Main+frame.stp
Hardware/3D Printed/Stand.stl
Hardware/3D Printed/Electronics+shelf.stl
Hardware/3D Printed/esc+holder.stl
Hardware/step/Water+Resistent+cover.stp
Hardware/3D Printed/carrier+payload.stl
Hardware/step/Battery+holder.stp
Hardware/3D Printed/Dropper payload.3mf.stl
Hardware/3D Printed/Wifi payload.3mf.stl
Hardware/3D Printed/payload+rail+system.stl
Hardware/3D Printed/wifi+payload.stl
Hardware/step/Combination.3mf.stl
Hardware/step/Cooling+system.stp
Hardware/step/payload+rail+system.stp

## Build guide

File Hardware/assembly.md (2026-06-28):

# Assembly Instructions
## Pre Requisites 
-> All parts printed  \
-> all PCBs assembled \
-> The BOTWING 60A esc (or similar) \
-> FlySky i6 Radio (or similar)  \
-> Raspberry PI 5 \
-> Everything else in the BOM \
---
## Step 1: Main Frame
So start with the main frame. The side where the footprint is angular is the front side, while the rounded part is the back. \
You will see 2 cut outs there. The one towards the front is for the PN432 NFC and the one near the back is for the payload PCB. \
Wire up the pogo pins and nfc to the payload pcb as per the schematics and wiring diagrams. \
Screw in the Landing gear at the bottom
\
Screw in the motor mounts and then the motors, make sure to put the wires into the pipes (may be hard). You will probably have to extend the wires. \
Then add the battery mount and the battery. (Note: the battery mount only works for the specific battery in the bom. If you change the battery, you have to change the mount) \
---
## Step 2: Electronics Shelf
Add the PI5 towaeds the back, and the FC + ESC towards the front on top of each other. Screw in and Wire things up as per the diagram. \
You must use metallic screws for the fc + esc, your fc wont be grounded otherwise. \ 
Add the PI5  active cooler ontop of the pi5. 
---
## Step 3: Waterproof Cover
Tape the picam to the hole at the front. Wire it up as needed. Add the LIDAR on top in its compartment, and in the gps box add the gps and rc, and wire them up.
---
## Step 4: Assembly
Add 55mm 3.5mm diameter alumiunium/nylon standoffs to the bottom of the main frame. Then add the electronics shelf on top of the battery holder. \
Add the waterproof cover on top (make sure its screwed in). 

You should be done!

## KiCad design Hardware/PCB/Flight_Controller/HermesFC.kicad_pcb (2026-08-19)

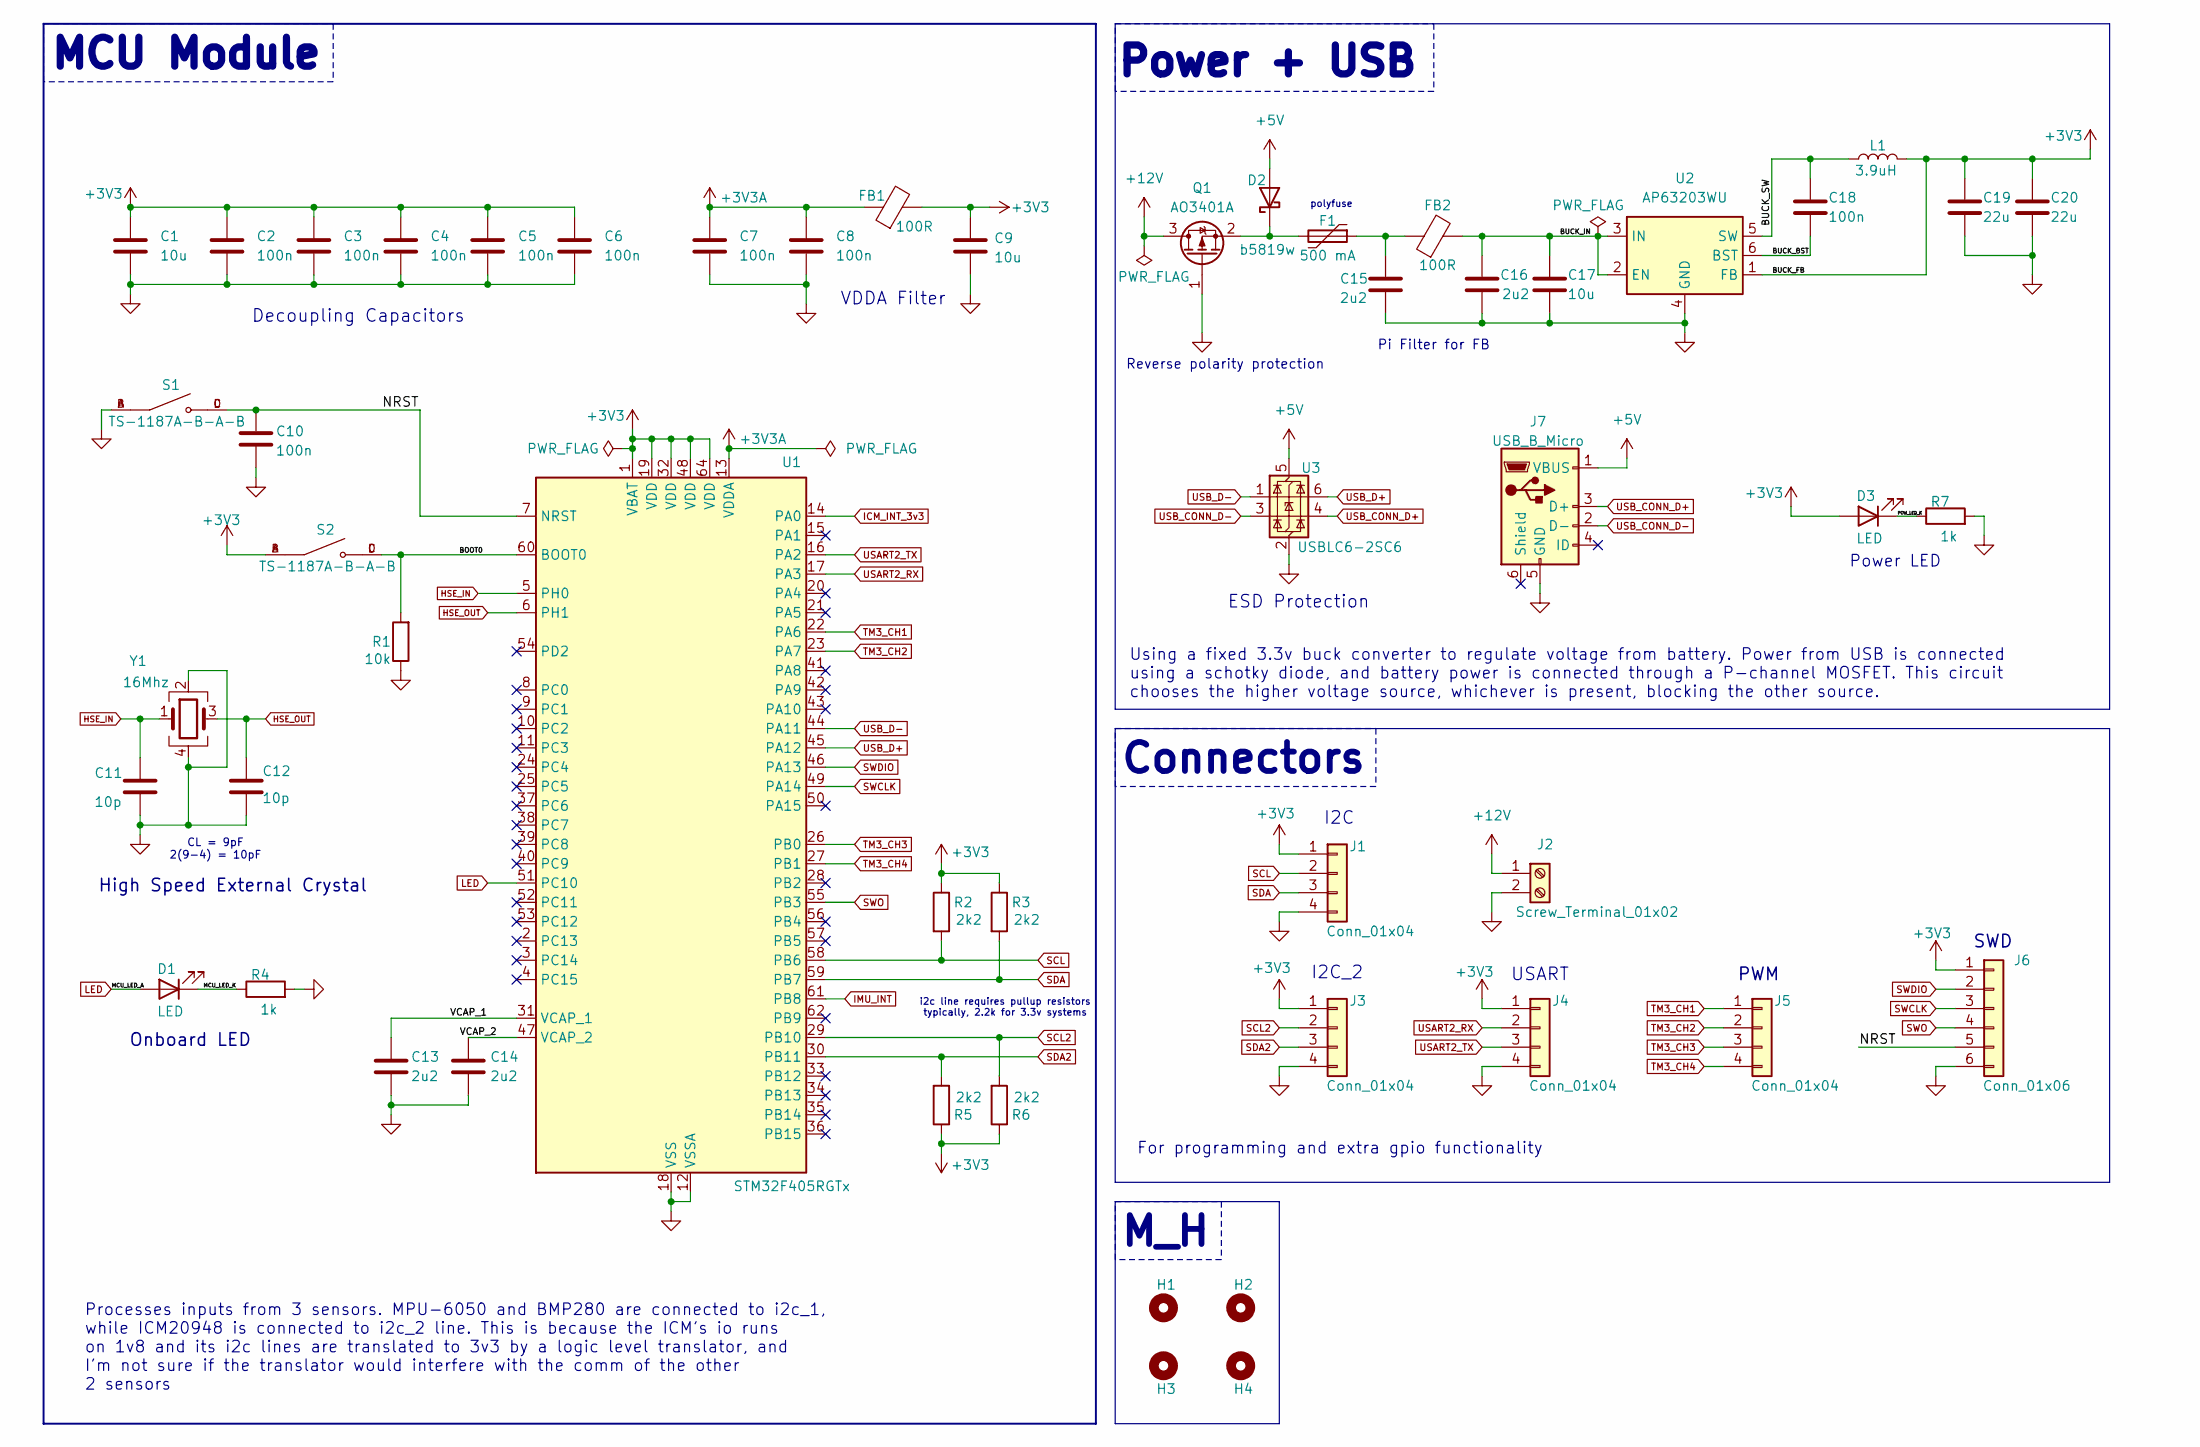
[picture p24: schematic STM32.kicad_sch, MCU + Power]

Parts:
C1, C9, C17: 10u; C_0603_1608Metric
C2, C3, C4, C5, C6, C7, C8, C10: 100n; C_0402_1005Metric
C11, C12: 10p; C_0603_1608Metric
C13, C14, C15, C16: 2u2; C_0603_1608Metric
C18: 100n; C_0805_2012Metric
C19, C20: 22u; C_0805_2012Metric
D1, D3: LED; LED_0603_1608Metric
D2: b5819w; D_SOD-123
F1: 500 mA; Fuse_0603_1608Metric
FB1, FB2: 100R; L_0805_2012Metric
H1, H2, H3, H4: MountingHole; MountingHole_4.3mm_M4_Pad_Via
J1, J3, J4, J5: Conn_01x04; PinSocket_1x04_P2.54mm_Vertical
J2: Screw_Terminal_01x02; TerminalBlock_Xinya_XY308-2.54-2P_1x02_P2.54mm_Horizontal
J6: Conn_01x06; PinSocket_1x06_P2.54mm_Vertical
J7: USB_B_Micro; USB_Micro-B_Amphenol_10118193-0001LF_Horizontal
L1: 3.9uH; L_Taiyo-Yuden_MD-5050
Q1: AO3401A; SOT-23
R1: 10k; R_0603_1608Metric
R2, R3, R5, R6: 2k2; R_0603_1608Metric
R4, R7: 1k; R_0603_1608Metric
S1, S2: TS-1187A-B-A-B; SW_TS-1187A-B-A-B; PARTREV A0
U1: STM32F405RGTx; LQFP-64_10x10mm_P0.5mm
U2: AP63203WU; TSOT-23-6
U3: USBLC6-2SC6; SOT-23-6
Y1: 16Mhz; Crystal_SMD_3225-4Pin_3.2x2.5mm

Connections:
+3V3: C1.1, C2.1, C3.1, C4.1, C5.1, C6.1, C9.1, C19.1, C20.1, D3.2 (A), FB1.2, J1.1, J3.1, J4.1, J6.1, L1.2, R2.1, R3.1, R5.1, R6.1, S2.A, S2.B, U1.1 (VBAT), U1.19 (VDD), U1.32 (VDD), U1.48 (VDD), U1.64 (VDD), U2.1 (FB); also elsewhere on the board
+3V3A: C7.1, C8.1, FB1.1, U1.13 (VDDA)
+5V: D2.2 (A), J7.1 (VBUS), U3.5 (VBUS)
+12V: J2.1, Q1.3 (D)
/STM32/BOOT0: R1.2, S2.C, S2.D, U1.60 (BOOT0)
/STM32/BUCK_BST: C18.2, U2.6 (BST)
/STM32/BUCK_IN: C16.1, C17.1, FB2.2, U2.2 (EN), U2.3 (IN)
/STM32/BUCK_SW: C18.1, L1.1, U2.5 (SW)
/STM32/MCU_LED_K: D1.1 (K), R4.1
/STM32/NRST: C10.1, J6.5, S1.C, S1.D, U1.7 (NRST)
/STM32/POW_LED_K: D3.1 (K), R7.1
/STM32/VCAP_1: C13.1, U1.31 (VCAP_1)
/STM32/VCAP_2: C14.1, U1.47 (VCAP_2)
GND: C1.2, C2.2, C3.2, C4.2, C5.2, C6.2, C7.2, C8.2, C9.2, C10.2, C11.2, C12.2, C13.2, C14.2, C15.2, C16.2, C17.2, C19.2, C20.2, H1.1, H2.1, H3.1, H4.1, J1.4, J2.2, J3.4, J4.4, J6.6, J7.5 (GND), Q1.1 (G), R1.1, R4.2, R7.2, S1.A, S1.B, U1.12 (VSSA), U1.18 (VSS), U1.63 (VSS), U2.4 (GND), U3.2 (GND), Y1.2, Y1.4; also elsewhere on the board
HSE_IN: C11.1, U1.5 (PH0), Y1.1
HSE_OUT: C12.1, U1.6 (PH1), Y1.3
ICM_INT_3v3: U1.14 (PA0); also elsewhere on the board
IMU_INT: U1.61 (PB8); also elsewhere on the board
LED: D1.2 (A), U1.51 (PC10)
unnamed: C15.1, F1.1, FB2.1
unnamed: D2.1 (K), F1.2, Q1.2 (S)
SCL: J1.2, R2.2, U1.58 (PB6); also elsewhere on the board
SCL2: J3.2, R6.2, U1.29 (PB10); also elsewhere on the board
SDA: J1.3, R3.2, U1.59 (PB7); also elsewhere on the board
SDA2: J3.3, R5.2, U1.30 (PB11); also elsewhere on the board
SWCLK: J6.3, U1.49 (PA14)
SWDIO: J6.2, U1.46 (PA13)
SWO: J6.4, U1.55 (PB3)
TM3_CH1: J5.1, U1.22 (PA6)
TM3_CH2: J5.2, U1.23 (PA7)
TM3_CH3: J5.3, U1.26 (PB0)
TM3_CH4: J5.4, U1.27 (PB1)
USART2_RX: J4.2, U1.17 (PA3)
USART2_TX: J4.3, U1.16 (PA2)
USB_CONN_D+: J7.3 (D+), U3.4 (I/O2)
USB_CONN_D-: J7.2 (D-), U3.3 (I/O2)
USB_D+: U1.45 (PA12), U3.6 (I/O1)
USB_D-: U1.44 (PA11), U3.1 (I/O1)

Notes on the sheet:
polyfuse
ESD Protection
Decoupling Capacitors
CL = 9pF 2(9-4) = 10pF
Using a fixed 3.3v buck converter to regulate voltage from battery. Power from USB is connected using a schotky diode, and battery power is connected through a P-channel MOSFET. This circuit chooses the higher voltage source, whichever is present, blocking the other source.
VDDA Filter
Onboard LED
i2c line requires pullup resistors typically, 2.2k for 3.3v systems
USART
Processes inputs from 3 sensors. MPU-6050 and BMP280 are connected to i2c_1, while ICM20948 is connected to i2c_2 line. This is because the ICM's io runs on 1v8 and its i2c lines are translated to 3v3 by a logic level translator, and I'm not sure if the translator would interfere with the comm of t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
M_H
Pi Filter for FB
For programming and extra gpio functionality
I2C
SWD
High Speed External Crystal
Power LED
PWM
Reverse polarity protection
MCU Module
Connectors
Power + USB
I2C_2

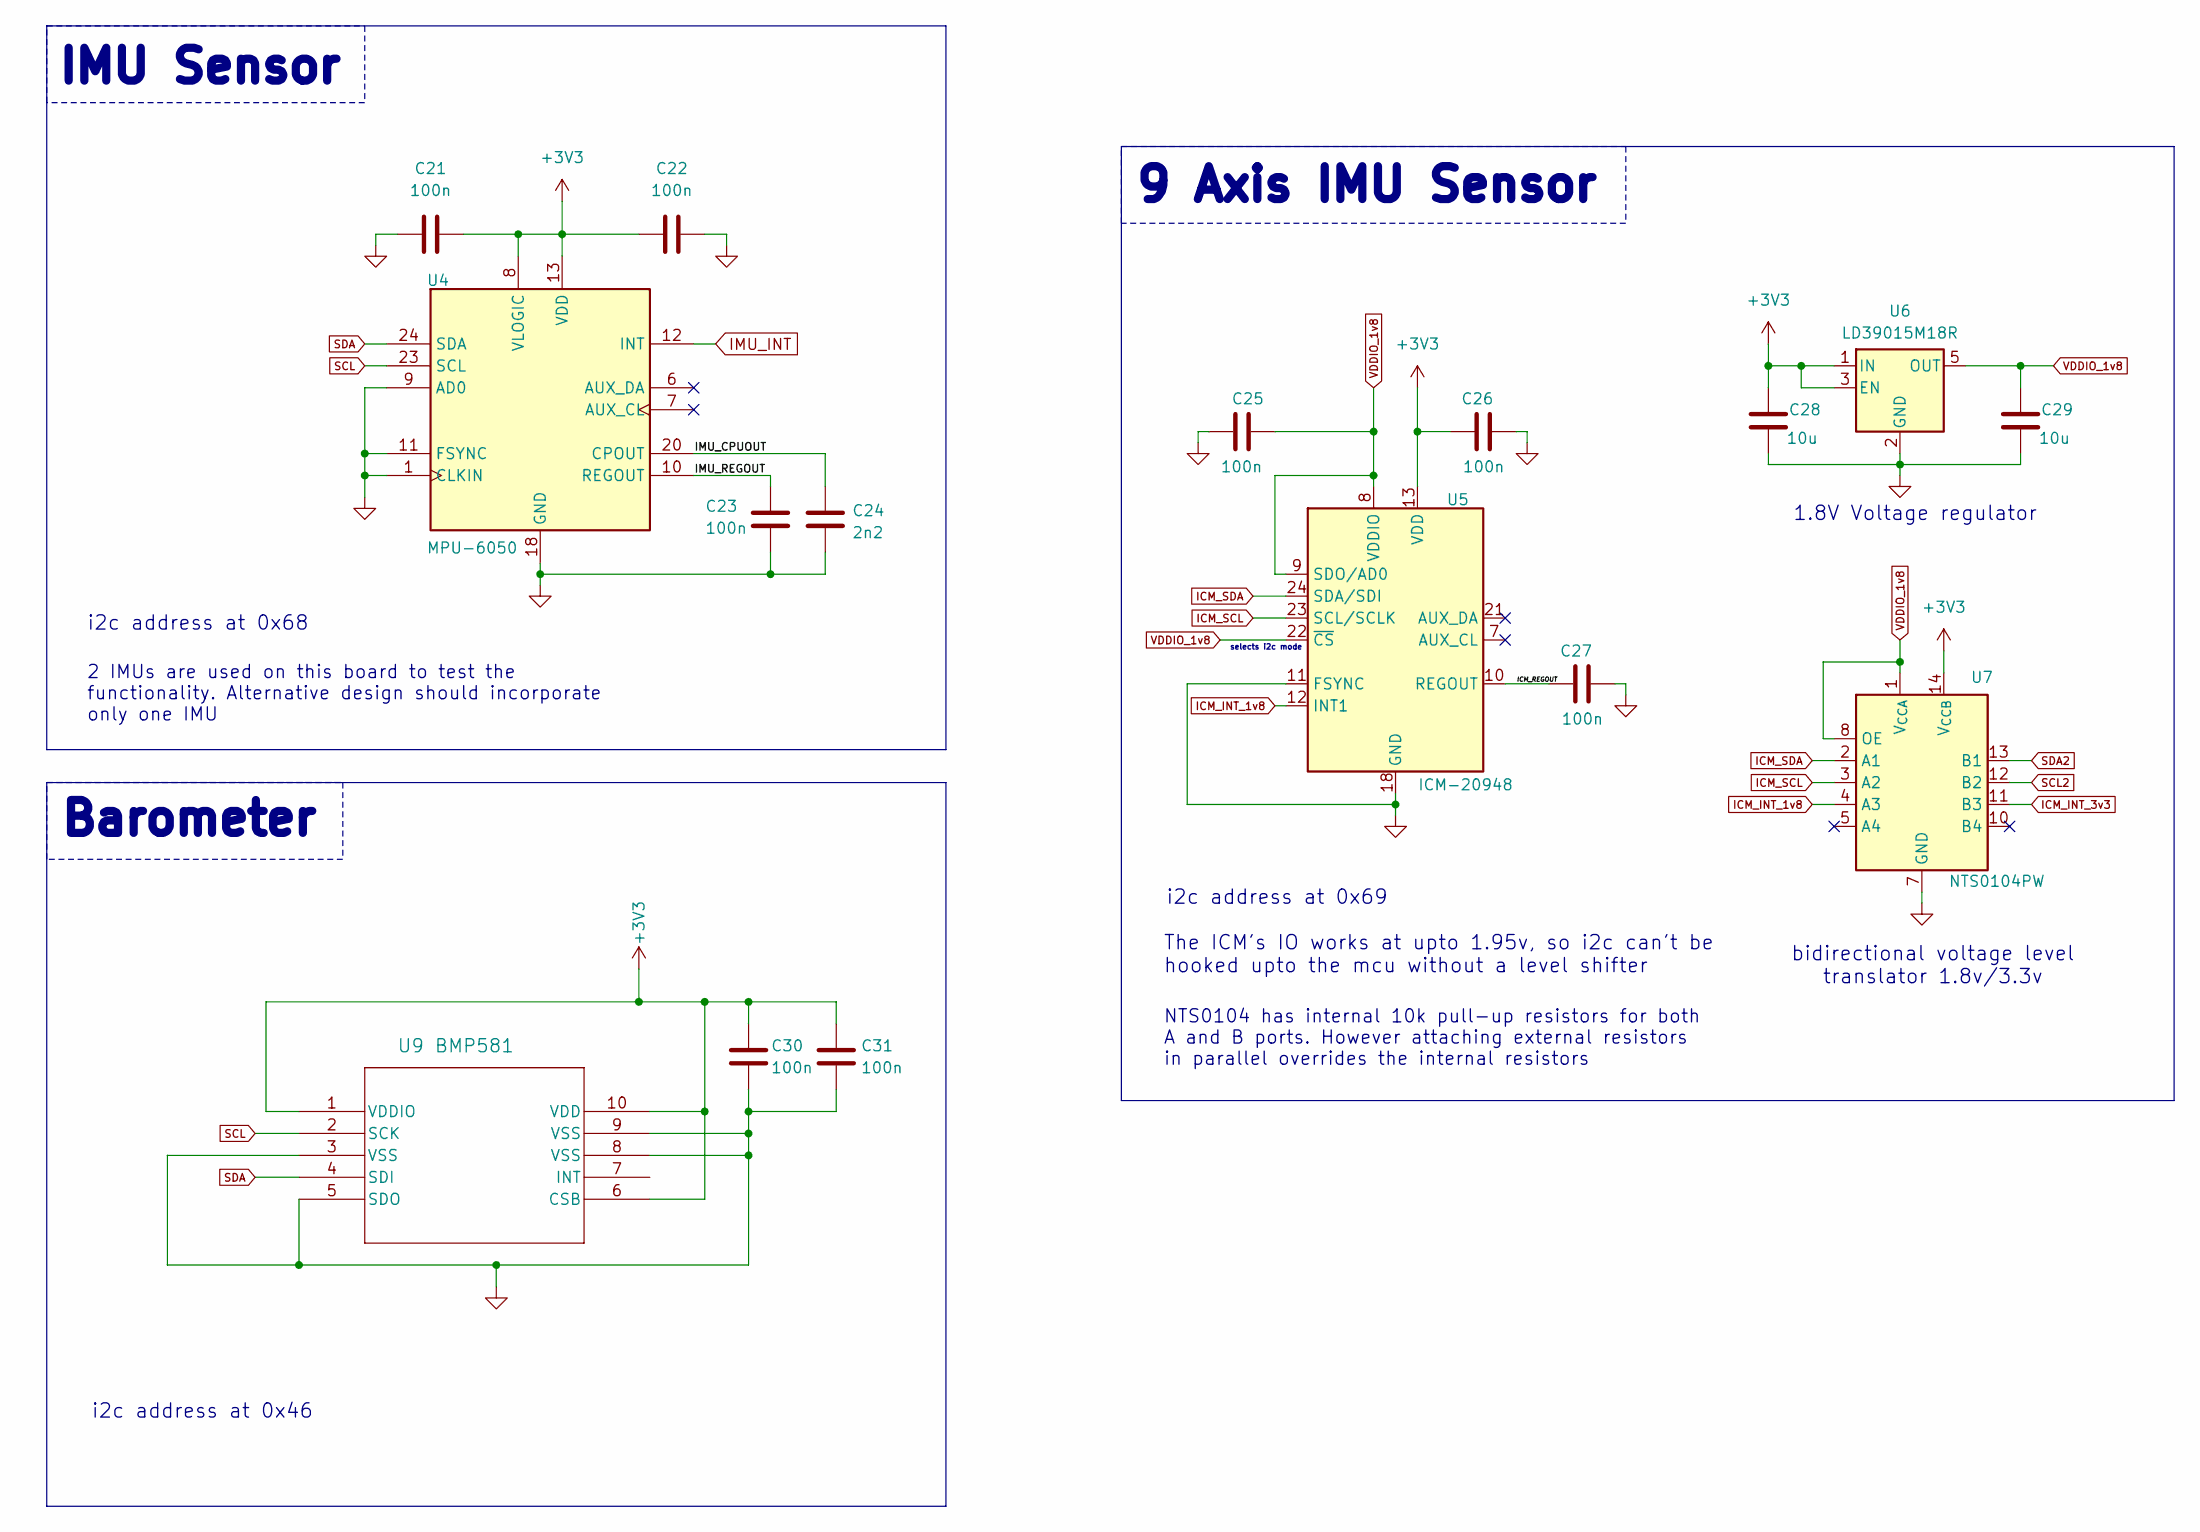
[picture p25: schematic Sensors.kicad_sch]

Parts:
C21, C22, C23, C25, C26, C27, C30, C31: 100n; C_0402_1005Metric
C24: 2n2; C_0603_1608Metric
C28, C29: 10u; C_0603_1608Metric
U4: MPU-6050; InvenSense_QFN-24_4x4mm_P0.5mm
U5: ICM-20948; InvenSense_QFN-24_3x3mm_P0.4mm
U6: LD39015M18R; SOT-23-5
U7: NTS0104PW; TSSOP-14_4.4x5mm_P0.65mm
U9: BMP581; QFN10_BMP581_BOS

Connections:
+3V3: C21.2, C22.1, C26.1, C28.1, C30.1, C31.2, U4.8 (VLOGIC), U4.13 (VDD), U5.13 (VDD), U6.1 (IN), U6.3 (EN), U7.14 (V_{CCB}), U9.1 (VDDIO), U9.6 (CSB), U9.10 (VDD); also elsewhere on the board
/Sensors/ICM_REGOUT: C27.1, U5.10 (REGOUT)
/Sensors/IMU_CPUOUT: C24.1, U4.20 (CPOUT)
/Sensors/IMU_REGOUT: C23.1, U4.10 (REGOUT)
GND: C21.1, C22.2, C23.2, C24.2, C25.2, C26.2, C27.2, C28.2, C29.2, C30.2, C31.1, U4.1 (CLKIN), U4.9 (AD0), U4.11 (FSYNC), U4.18 (GND), U5.11 (FSYNC), U5.18 (GND), U5.20 (GND), U6.2 (GND), U7.7 (GND), U9.3 (VSS), U9.5 (SDO), U9.8 (VSS), U9.9 (VSS); also elsewhere on the board
ICM_INT_1v8: U5.12 (INT1), U7.4 (A3)
ICM_INT_3v3: U7.11 (B3); also elsewhere on the board
ICM_SCL: U5.23 (SCL/SCLK), U7.3 (A2)
ICM_SDA: U5.24 (SDA/SDI), U7.2 (A1)
IMU_INT: U4.12 (INT); also elsewhere on the board
SCL: U4.23 (SCL), U9.2 (SCK); also elsewhere on the board
SCL2: U7.12 (B2); also elsewhere on the board
SDA: U4.24 (SDA), U9.4 (SDI); also elsewhere on the board
SDA2: U7.13 (B1); also elsewhere on the board
VDDIO_1v8: C25.1, C29.1, U5.8 (VDDIO), U5.9 (SDO/AD0), U5.22 (~CS), U6.5 (OUT), U7.1 (V_{CCA}), U7.8 (OE)

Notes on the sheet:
9 Axis IMU Sensor
i2c address at 0x46
1.8V Voltage regulator
2 IMUs are used on this board to test the functionality. Alternative design should incorporate only one IMU
NTS0104 has internal 10k pull-up resistors for both A and B ports. However attaching external resistors in parallel overrides the internal resistors
IMU Sensor
i2c address at 0x69
Barometer
i2c address at 0x68
selects i2c mode
bidirectional voltage level translator 1.8v/3.3v
The ICM's IO works at upto 1.95v, so i2c can't be hooked upto the mcu without a level shifter

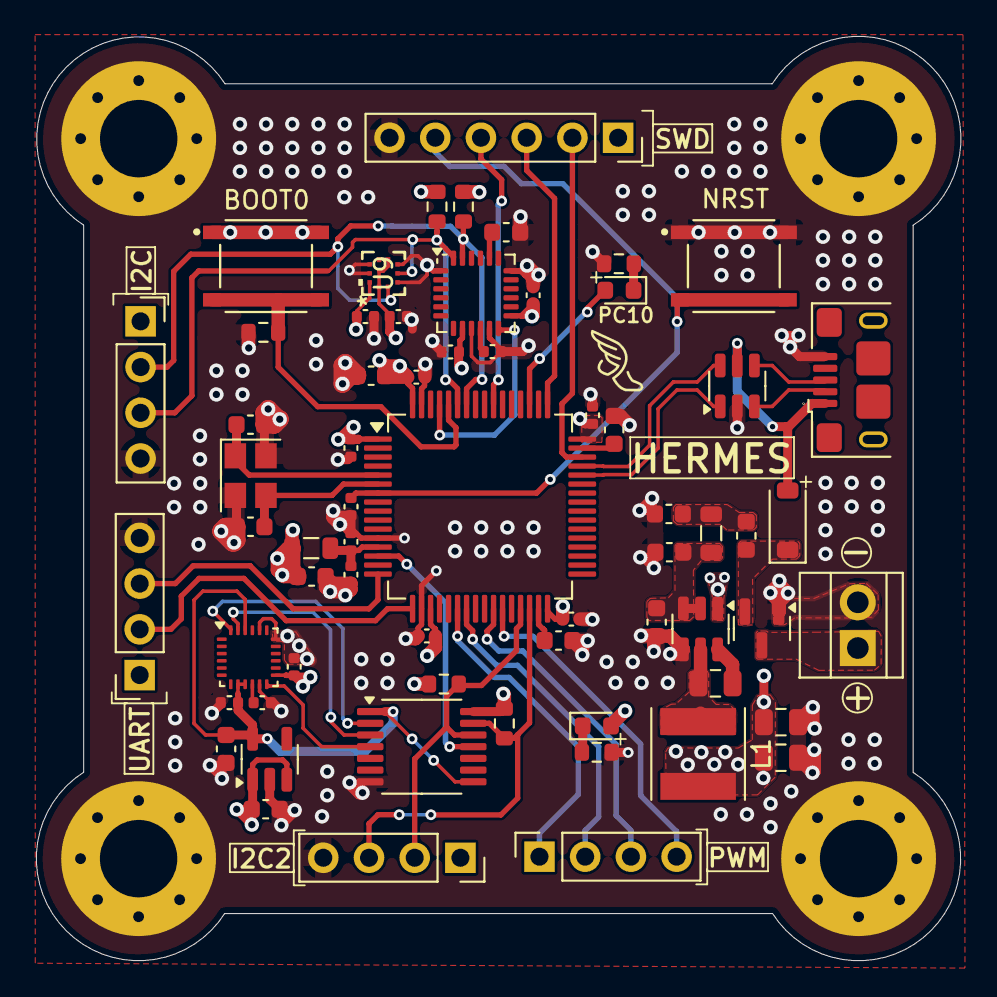
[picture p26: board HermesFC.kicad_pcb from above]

Board: 4 copper layers, 51.4 x 51.3 mm, 68 parts (0 on the bottom side), 45 nets.

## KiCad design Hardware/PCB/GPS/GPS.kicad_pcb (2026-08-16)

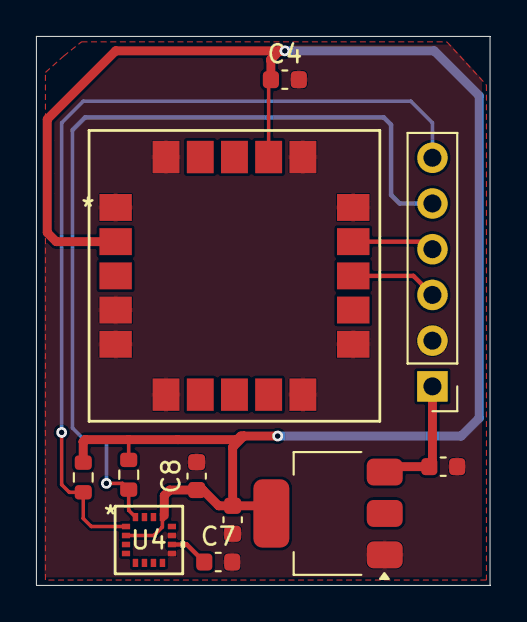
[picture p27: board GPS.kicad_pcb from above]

Board: 2 copper layers, 25.2 x 30.5 mm, 11 parts (0 on the bottom side), 8 nets.

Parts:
C1: 10uF; C_0603_1608Metric
C2: 22uF; C_0603_1608Metric
C4: 100nF; C_0603_1608Metric
C7: 10uf; C_0603_1608Metric
C8: 1 uf; C_0603_1608Metric
J1: Conn_01x06_Socket; PinHeader_1x06_P2.54mm_Vertical
R1, R2: 4.7kΩ; R_0603_1608Metric
U1: SAM-M10Q-00B; SAM-M10Q_UBL
U2: AMS1117-3.3; SOT-223-3_TabPin2
U4: MMC5983MA; MMC5983MA_MEM

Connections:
3v3: C2.1, C4.1, C8.1, R1.1, R2.1, U1.2 (V_IO), U1.17 (VCC), U2.2 (VO), U4.2 (VDD), U4.4 (SPI_CS), U4.13 (VDDIO)
/+5v: C1.1, J1.1, U2.3 (VI)
/comp_scl: J1.6, R2.2, U4.1 (SCL/SPI_SCK)
/comp_sda: J1.5, R1.2, U4.16 (SDA/SPI_SDI)
/gps_rxd: J1.4, U1.14 (RXD)
/gps_txd: J1.3, U1.13 (TXD)
unnamed: C7.1, U4.10 (CAP)
gnd: C1.2, C2.2, C4.2, C7.2, C8.2, J1.2, U1.1 (GND), U1.4 (GND), U1.5 (GND), U1.6 (GND), U1.10 (GND), U1.11 (GND), U1.15 (GND), U1.16 (GND), U1.20 (GND), U2.1 (GND), U4.9 (GND), U4.11 (GND)

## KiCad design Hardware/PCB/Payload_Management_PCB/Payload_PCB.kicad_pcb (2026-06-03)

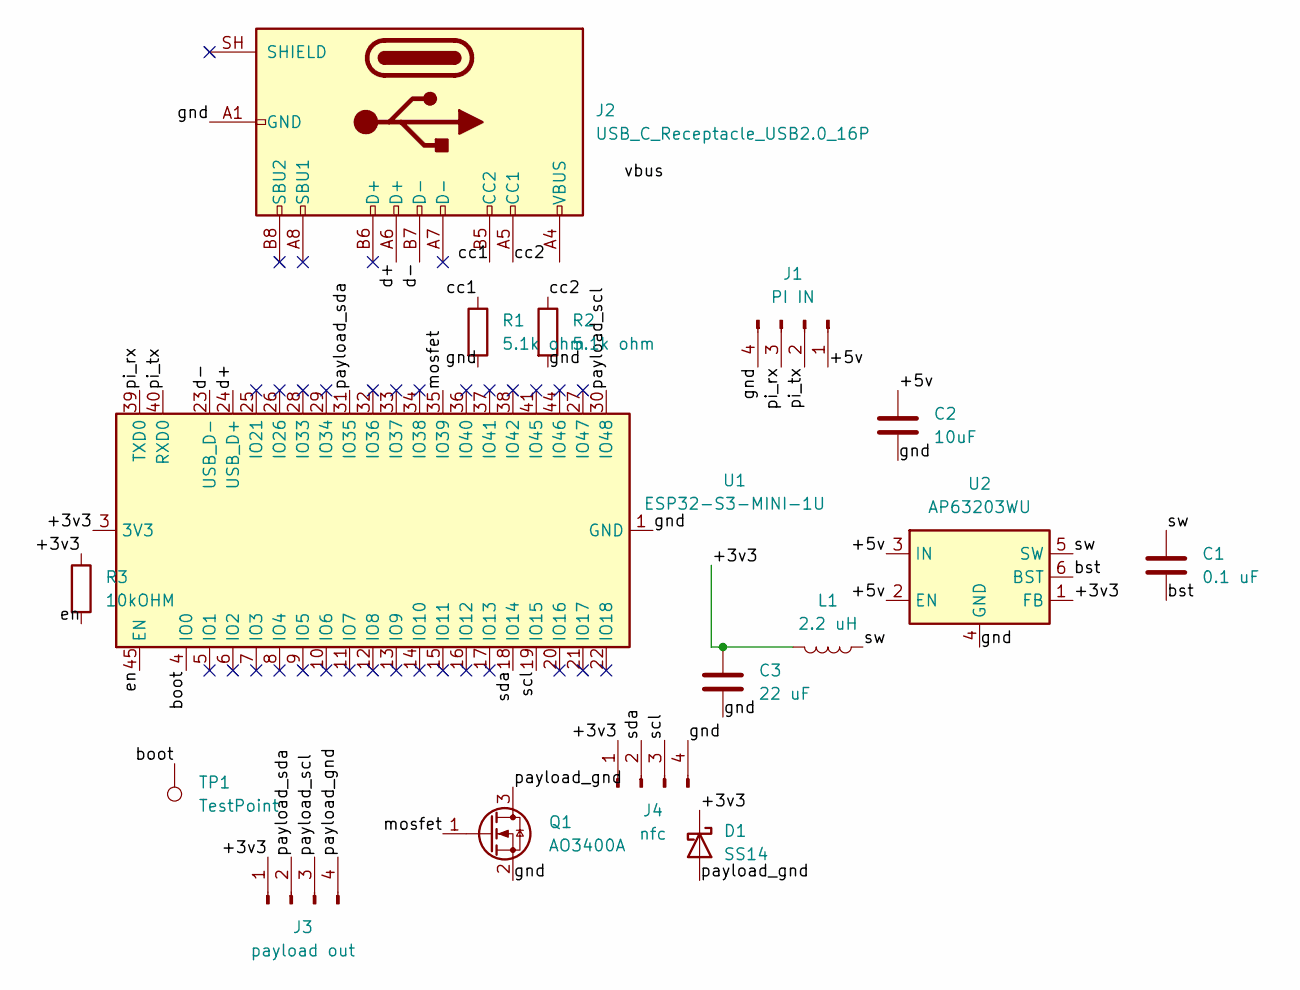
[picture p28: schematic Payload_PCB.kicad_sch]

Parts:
C1: 0.1 uF; C_0603_1608Metric
C2: 10uF; C_0603_1608Metric
C3: 22 uF; C_0603_1608Metric
D1: SS14; D_SMA
J1: PI IN; PinHeader_1x04_P2.54mm_Vertical
J2: USB_C_Receptacle_USB2.0_16P; USB_C_Receptacle_GCT_USB4105-xx-A_16P_TopMnt_Horizontal
J3: payload out; PinHeader_1x04_P2.54mm_Vertical
J4: nfc; PinHeader_1x04_P2.54mm_Vertical
L1: 2.2 uH; L_0603_1608Metric
Q1: AO3400A; SOT-23
R1, R2: 5.1k ohm; R_0603_1608Metric
R3: 10kOHM; R_0603_1608Metric
TP1: TestPoint; TestPoint_Pad_D1.0mm
U1: ESP32-S3-MINI-1U; ESP32-S2-MINI-1U
U2: AP63203WU; TSOT-23-6

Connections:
/+3v3: C3.1, D1.1 (K), J3.1, J4.1, L1.2, R3.1, U1.3 (3V3), U2.1 (FB)
/+5v: C2.1, J1.1, U2.2 (EN), U2.3 (IN)
/boot: TP1.1 (1_1), U1.4 (IO0)
/bst: C1.2, U2.6 (BST)
/cc1: J2.B5 (CC2), R1.1
/cc2: J2.A5 (CC1), R2.1
/d+: J2.A6 (D+), U1.24 (USB_D+)
/d-: J2.B7 (D-), U1.23 (USB_D-)
/en: R3.2, U1.45 (EN)
/gnd: C2.2, C3.2, J1.4, J2.A1 (GND), J2.A12 (GND), J2.B1 (GND), J2.B12 (GND), J4.4, Q1.2 (S), R1.2, R2.2, U1.1 (GND), U1.2 (GND), U1.42 (GND), U1.43 (GND), U1.46 (GND), U1.47 (GND), U1.48 (GND), U1.49 (GND), U1.50 (GND), U1.51 (GND), U1.52 (GND), U1.53 (GND), U1.54 (GND), U1.55 (GND), U1.56 (GND), U1.57 (GND), U1.58 (GND), U1.59 (GND), U1.60 (GND), U1.61 (GND), U1.62 (GND), U1.63 (GND), U1.64 (GND), U1.65 (GND), U2.4 (GND)
/mosfet: Q1.1 (G), U1.35 (IO39)
/payload_gnd: D1.2 (A), J3.4, Q1.3 (D)
/payload_scl: J3.3, U1.30 (IO48)
/payload_sda: J3.2, U1.31 (IO35)
/pi_rx: J1.3, U1.39 (TXD0)
/pi_tx: J1.2, U1.40 (RXD0)
/scl: J4.3, U1.19 (IO15)
/sda: J4.2, U1.18 (IO14)
/sw: C1.1, L1.1, U2.5 (SW)
unnamed: J2.A4 (VBUS), J2.A9 (VBUS), J2.B4 (VBUS), J2.B9 (VBUS)

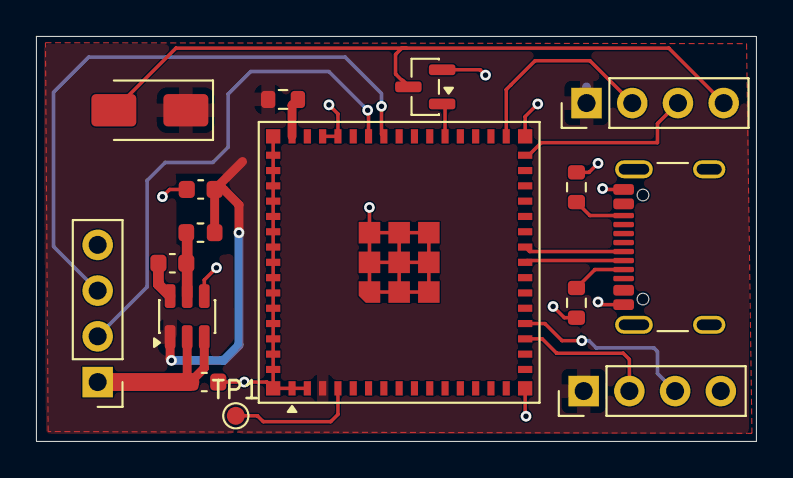
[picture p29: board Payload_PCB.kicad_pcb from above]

Board: 2 copper layers, 40.0 x 22.5 mm, 16 parts (0 on the bottom side), 20 nets.

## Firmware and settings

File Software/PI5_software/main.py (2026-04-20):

import argparse
import logging
import os
import signal
import sys
import time
import requests
sys.path.insert(0, os.path.dirname(os.path.dirname(os.path.abspath(__file__))))
from shared.config import (
    MOCK_MODE,
    MAVLINK_CONNECTION,
    MAVLINK_BAUD,
    LIDAR_D500_PORT,
    TF_LUNA_PORT,
    LOOP_HZ,
    TARGET_HEADING,
    DEFAULT_ALTITUDE_M,
    BACKEND_URL,
)
if MOCK_MODE:
    from mock_hardware import MockMAVLinkInterface as MAVLinkInterface
    from mock_hardware import MockSensorManager as SensorManager
    import mock_hardware as _mock_hw
else:
    from mavlink_interface import MAVLinkInterface
    from sensor_manager import SensorManager
    _mock_hw = None
from lidar_processing import process_scan, process_tf_luna
from decision_engine import DecisionEngine
from navigation import NavigationController
logging.basicConfig(
    level=logging.INFO,
    format="%(asctime)s [%(levelname)s] %(name)s: %(message)s",
    handlers=[logging.StreamHandler(sys.stdout), logging.FileHandler("/tmp/streetsafe.log")],
)
logger = logging.getLogger("main")
_running = True
def _handle_signal(sig, _frame):
    global _running
    logger.info("Shutdown signal received — stopping loop")
    _running = False
_COLORS = {
    "green":  "\033[92m",
    "yellow": "\033[93m",
    "red":    "\033[91m",
    "cyan":   "\033[96m",
    "bold":   "\033[1m",
    "reset":  "\033[0m",
}
def _c(color, text):
    return f"{_COLORS.get(color, '')}{text}{_COLORS['reset']}"
STATE_COLORS = {
    "NAVIGATING": "green",
    "AVOIDING":   "yellow",
    "HOVERING":   "cyan",
    "EMERGENCY":  "red",
}
def _print_status(decision, gps, alt):
    state = decision["state"]
    color = STATE_COLORS.get(state, "reset")
    hdg = decision["safe_heading"]
    hdg_str = f"{hdg:.0f}°" if hdg is not None else "N/A"
    lat = gps["lat"] if gps else "?"
    lon = gps["lon"] if gps else "?"
    a = alt["alt_relative"] if alt else "?"
    print(
        f"  {_c(color, f'[{state:11s}]')}  "
        f"Heading: {_c('bold', hdg_str):6s}  "
        f"Obstacles: {_c('red' if decision['obstacle_count'] else 'green', str(decision['obstacle_count']))}  "
        f"Terrain: {decision['terrain_class']:10s}  "
        f"GPS: ({lat}, {lon})  Alt: {a} m"
    )
    for alert in decision.get("alerts", []):
        lv = alert["level"].upper()
        icon = "🚨" if lv == "CRITICAL" else "⚠️ " if lv == "WARNING" else "ℹ️ "
        print(f"       {icon}  {_c('red' if lv == 'CRITICAL' else 'yellow', alert['message'])}")
def _announce_action(action, safe_heading, target_heading):
    if action == "NAVIGATE":
        print(f"  ✈  Flying toward heading {target_heading:.0f}° — path is clear.")
    elif action == "AVOID":
        print(f"  ↩  Obstacle detected! Rerouting: {target_heading:.0f}° → {safe_heading:.0f}°")
    elif action == "HOVER":
        print(f"  ⏸  All directions blocked — holding position.")
    elif action == "STOP":
        print(f"  🛑  EMERGENCY STOP — object too close!")
_t_scene = 0.0
_t_speed = 0.0
_t_loc = 0.0
def _push_to_backend(decision, scan, gps, alt):
    dm = {str(k): v for k, v in scan.get("distance_map", {}).items()}
    payload = {
        "state":          decision["state"],
        "lat":            gps["lat"] if gps else None,
        "lon":            gps["lon"] if gps else None,
        "altitude_m":     alt["alt_relative"] if alt else None,
        "heading_deg":    decision.get("safe_heading"),
        "groundspeed_ms": alt["groundspeed"] if alt else None,
        "action":         decision.get("action"),
        "alerts":         decision.get("alerts", []),
        "obstacles":      decision.get("obstacles", []),
        "terrain_class":  scan.get("terrain_class", "unknown"),
        "distance_map":   dm,
    }
    try:
        requests.post(f"{BACKEND_URL}/status/update", json=payload, timeout=0.5)
    except Exception:
        pass
def _poll_scenario(sensors):
    global _t_scene
    if not MOCK_MODE:
        return
    now = time.time()
    if now - _t_scene < 1.0:
        return
    _t_scene = now
    try:
        resp = requests.get(f"{BACKEND_URL}/scenario", timeout=0.3)
        if resp.status_code == 200:
            sensors.set_scenario(resp.json().get("scenario", "clear"))
    except Exception:
        pass
def _poll_speed(nav):
    global _t_speed
    if not MOCK_MODE:
        return
    now = time.time()
    if now - _t_speed < 1.0:
        return
    _t_speed = now
    try:
        resp = requests.get(f"{BACKEND_URL}/speed", timeout=0.3)
        if resp.status_code == 200:
            spd = float(resp.json().get("speed", 2.0))
            if abs(nav.cruise_speed - spd) > 0.05:
                nav.cruise_speed = spd
                if _mock_hw:
                    _mock_hw.set_speed(spd)
    except Exception:
        pass
def _poll_location():
    global _t_loc
    if not MOCK_MODE:
        return
    now = time.time()
    if now - _t_loc < 1.0:
        return
    _t_loc = now
    try:
        resp = requests.get(f"{BACKEND_URL}/location", timeout=0.3)
        if resp.status_code == 200:
            loc = resp.json().get("location")
            if loc and _mock_hw:
                _mock_hw.set_position(loc["lat"], loc["lon"])
    except Exception:
        pass
def main():
    global _running
    parser = argparse.ArgumentParser()
    parser.add_argument(
        "--scenario",
        choices=["clear", "obstacle", "emergency"],
        default="clear",
    )
    args = parser.parse_args()
    signal.signal(signal.SIGINT, _handle_signal)
    signal.signal(signal.SIGTERM, _handle_signal)
    mode_label = _c("yellow", "MOCK") if MOCK_MODE else _c("green", "HARDWARE")
    print(_c("bold", f"\n{'═'*60}"))
    print(_c("bold", f"  StreetSafe Drone System  [{mode_label}\033[1m]"))
    print(_c("bold", f"{'═'*60}\n"))
    mav = MAVLinkInterface() if MOCK_MODE else MAVLinkInterface(MAVLINK_CONNECTION, MAVLINK_BAUD)
    if not mav.connect():
        logger.critical("Could not connect to flight controller — aborting")
        sys.exit(1)
    mav.set_guided_mode()
    sensors = SensorManager() if MOCK_MODE else SensorManager(d500_port=LIDAR_D500_PORT, tf_luna_port=TF_LUNA_PORT)
    logger.info(f"Sensor status: {sensors.initialize()}")
    if MOCK_MODE:
        sensors.set_scenario(args.scenario)
    engine = DecisionEngine(target_heading=TARGET_HEADING)
    nav = NavigationController(mav)
    interval = 1.0 / LOOP_HZ
    iteration = 0
    print(f"  Control loop: {LOOP_HZ} Hz   Target heading: {TARGET_HEADING}°\n")
    while _running:
        t0 = time.time()
        iteration += 1
        try:
            mav.update_heartbeat()
            if not mav.is_connected():
                logger.error("Lost MAVLink connection — retrying in 1 s")
                time.sleep(1.0)
                continue
            snap = sensors.read_all()
            lidar = snap.get("lidar_360")
            tf_raw = snap.get("lidar_front")
            scan = (
                process_scan(lidar)
                if lidar
                else {"obstacles": [], "distance_map": {}, "terrain_class": "unknown"}
            )
            tf = process_tf_luna(tf_raw)
            gps = mav.get_gps()
            alt = mav.get_altitude()
            decision = engine.evaluate(
                processed_scan=scan,
                tf_luna_data=tf,
                gps_data=gps,
                altitude_data=alt,
            )
            print(f"\n── Iteration {iteration:04d} ──────────────────────────────────────")
            _print_status(decision, gps, alt)
            _announce_action(decision["action"], decision["safe_heading"], decision["target_heading"])
            nav.execute_decision(decision)
            _poll_scenario(sensors)
            _poll_speed(nav)
            _poll_location()
            _push_to_backend(decision, scan, gps, alt)
        except Exception:
            logger.exception("Unhandled error in control loop — continuing")
        elapsed = time.time() - t0
        if interval - elapsed > 0:
            time.sleep(interval - elapsed)
    print("\n" + _c("bold", "Shutting down StreetSafe..."))
    nav._hover()
    sensors.shutdown()
    mav.disconnect()
    print(_c("green", "Shutdown complete.\n"))
if __name__ == "__main__":
    main()

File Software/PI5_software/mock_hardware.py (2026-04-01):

import math
import random
import time
_t0 = time.time()
def _elapsed():
    return time.time() - _t0
_lat = None
_lon = None
_speed = 2.0
def set_position(lat, lon):
    global _lat, _lon
    _lat = lat
    _lon = lon
    print(f"[MOCK] GPS pinned → ({lat:.6f}, {lon:.6f})")
def set_speed(speed):
    global _speed
    if abs(speed - _speed) > 0.05:
        _speed = speed
        print(f"[MOCK] Speed → {speed:.1f} m/s")
class MockMAVLinkInterface:
    def __init__(self):
        self._armed = False
        self._mode = "GUIDED"
        self._vx = 0.0
        self._vy = 0.0
    def connect(self):
        print("[MOCK] MAVLink: connected to simulated flight controller")
        return True
    def is_connected(self):
        return True
    def update_heartbeat(self):
        pass
    def disconnect(self):
        print("[MOCK] MAVLink: disconnected")
    def get_gps(self):
        t = _elapsed()
        if _lat is not None and _lon is not None:
            return {
                "lat": round(_lat + random.uniform(-0.000003, 0.000003), 7),
                "lon": round(_lon + random.uniform(-0.000003, 0.000003), 7),
                "alt_msl": round(50.0 + math.sin(t * 0.1) * 0.3, 2),
                "fix_type": 3,
                "satellites_visible": random.randint(9, 14),
            }
        spd = max(_speed, 0.1)
        lat = 28.6139 + (self._vx * t * 0.000009 * spd / 2.0)
        lon = 77.2090 + (self._vy * t * 0.000009 * spd / 2.0)
        return {
            "lat": round(lat + random.uniform(-0.000005, 0.000005), 7),
            "lon": round(lon + random.uniform(-0.000005, 0.000005), 7),
            "alt_msl": round(50.0 + math.sin(t * 0.1) * 0.3, 2),
            "fix_type": 3,
            "satellites_visible": random.randint(9, 14),
        }
    def get_altitude(self):
        t = _elapsed()
        return {
            "alt_relative": round(10.0 + math.sin(t * 0.2) * 0.2, 2),
            "groundspeed": round(_speed, 2),
            "airspeed": round(_speed + 0.3, 2),
            "heading": round((math.degrees(math.atan2(self._vy, self._vx)) + 360) % 360, 1),
            "throttle": 55,
        }
    def get_attitude(self):
        t = _elapsed()
        return {
            "roll": round(math.sin(t * 0.5) * 3.0, 2),
            "pitch": round(math.cos(t * 0.3) * 2.0, 2),
            "yaw": 0.0,
            "rollspeed": 0.0,
            "pitchspeed": 0.0,
            "yawspeed": 0.0,
        }
    def send_waypoint(self, lat, lon, alt):
        print(f"[MOCK] MAVLink: waypoint set → ({lat:.6f}, {lon:.6f}) alt={alt} m")
        return True
    def set_velocity(self, vx, vy, vz):
        self._vx = vx
        self._vy = vy
        return True
    def set_guided_mode(self):
        self._mode = "GUIDED"
        return True
    def arm(self):
        self._armed = True
        print("[MOCK] MAVLink: motors ARMED")
        return True
_SCENARIOS = {
    "clear":     [],
    "obstacle":  [(0, 1.2), (345, 1.5), (15, 1.8)],
    "emergency": [(0, 0.3), (350, 0.4), (10, 0.35)],
}
_CURRENT_SCENARIO = "clear"
class MockSensorManager:
    def __init__(self):
        pass
    def initialize(self):
        print("[MOCK] Sensors: D500 + TF-Luna simulated and ready")
        return {"d500": True, "tf_luna": True}
    @staticmethod
    def set_scenario(name):
        global _CURRENT_SCENARIO
        if name not in _SCENARIOS:
            raise ValueError(f"Unknown scenario {name!r}. Choose from {list(_SCENARIOS)}")
        if _CURRENT_SCENARIO != name:
            _CURRENT_SCENARIO = name
            print(f"[MOCK] Scenario → {name.upper()}")
    @staticmethod
    def _make_d500_scan():
        injected = {angle: dist for angle, dist in _SCENARIOS[_CURRENT_SCENARIO]}
        pts = []
        for deg in range(360):
            dm = 8.0
            for obs_angle, obs_dist in injected.items():
                if abs(deg - obs_angle) <= 10 or abs(deg - obs_angle - 360) <= 10:
                    dm = obs_dist + random.uniform(-0.05, 0.05)
                    break
            pts.append({
                "angle": float(deg),
                "distance_mm": int(dm * 1000),
                "intensity": random.randint(150, 255) if dm < 7 else random.randint(20, 80),
            })
        return {
            "sensor": "ldrobot_d500",
            "timestamp": time.time(),
            "frame_count": 30,
            "point_count": len(pts),
            "points": pts,
        }
    @staticmethod
    def _make_tf_luna():
        frontal = None
        for angle, dist in _SCENARIOS[_CURRENT_SCENARIO]:
            if abs(angle) <= 15:
                frontal = dist
                break
        d = (frontal if frontal else 8.0) + random.uniform(-0.02, 0.02)
        return {
            "sensor": "tf_luna",
            "timestamp": time.time(),
            "distance_cm": int(d * 100),
            "distance_m": round(d, 3),
            "amplitude": 2500,
            "chip_temp_c": round(35.0 + random.uniform(-0.5, 0.5), 1),
            "valid": True,
        }
    def read_lidar(self):
        return self._make_d500_scan()
    def read_tf_luna(self):
        return self._make_tf_luna()
    def read_all(self):
        return {"lidar_360": self.read_lidar(), "lidar_front": self.read_tf_luna(), "timestamp": time.time()}
    def shutdown(self):
        print("[MOCK] Sensors: shutdown")

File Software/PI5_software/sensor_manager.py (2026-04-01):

import struct
import time
import serial
class LDRobotD500:
    FRAME_HEADER = 0x54
    FRAME_TYPE = 0x2C
    BAUD_RATE = 230_400
    FRAME_SIZE = 47
    POINTS_PER_FRAME = 12
    def __init__(self, port="/dev/ttyUSB0"):
        self.port = port
        self._serial = None
        self._connected = False
    def connect(self):
        try:
            self._serial = serial.Serial(self.port, baudrate=self.BAUD_RATE, timeout=1.0)
            self._connected = True
            return True
        except serial.SerialException as e:
            print(f"D500 connect failed: {e}")
            return False
    def _parse_frame(self, data):
        if len(data) < self.FRAME_SIZE:
            return None
        if data[0] != self.FRAME_HEADER or data[1] != self.FRAME_TYPE:
            return None
        rpm = struct.unpack_from("<H", data, 2)[0] / 100.0
        a0 = struct.unpack_from("<H", data, 4)[0] / 100.0
        a1 = struct.unpack_from("<H", data, 40)[0] / 100.0
        ts = struct.unpack_from("<H", data, 42)[0]
        pts = []
        for i in range(self.POINTS_PER_FRAME):
            offset = 6 + i * 3
            pts.append({"distance_mm": struct.unpack_from("<H", data, offset)[0], "intensity": data[offset + 2]})
        n = len(pts) - 1
        step = ((a1 - a0) if a0 <= a1 else (a1 + 360.0 - a0)) / n if n > 0 else 0
        for i, pt in enumerate(pts):
            pt["angle"] = (a0 + i * step) % 360.0
        return {"speed_rpm": rpm, "start_angle": a0, "end_angle": a1, "timestamp_ms": ts, "points": pts}
    def read_scan(self):
        if not self._connected or self._serial is None:
            return None
        pts = []
        frames = 0
        end = time.time() + 2.0
        while frames < 30 and time.time() < end:
            b = self._serial.read(1)
            if not b or b[0] != self.FRAME_HEADER:
                continue
            rest = self._serial.read(self.FRAME_SIZE - 1)
            if len(rest) < self.FRAME_SIZE - 1:
                continue
            parsed = self._parse_frame(b + rest)
            if parsed:
                pts.extend(parsed["points"])
                frames += 1
        if not pts:
            return None
        return {
            "sensor": "ldrobot_d500",
            "timestamp": time.time(),
            "frame_count": frames,
            "point_count": len(pts),
            "points": pts,
        }
    def disconnect(self):
        if self._serial and self._serial.is_open:
            self._serial.close()
        self._connected = False
class TFLuna:
    FRAME_HEADER = 0x59
    BAUD_RATE = 115_200
    FRAME_SIZE = 9
    def __init__(self, port="/dev/ttyAMA1"):
        self.port = port
        self._serial = None
        self._connected = False
    def connect(self):
        try:
            self._serial = serial.Serial(self.port, baudrate=self.BAUD_RATE, timeout=1.0)
            self._connected = True
            return True
        except serial.SerialException as e:
            print(f"TF-Luna connect failed: {e}")
            return False
    @staticmethod
    def _checksum(frame):
        return sum(frame[:8]) & 0xFF
    def read_distance(self):
        if not self._connected or self._serial is None:
            return None
        try:
            while True:
                b1 = self._serial.read(1)
                if not b1:
                    return None
                if b1[0] != self.FRAME_HEADER:
                    continue
                b2 = self._serial.read(1)
                if not b2:
                    return None
                if b2[0] == self.FRAME_HEADER:
                    break
            body = self._serial.read(self.FRAME_SIZE - 2)
            if len(body) < self.FRAME_SIZE - 2:
                return None
            frame = b1 + b2 + body
            if self._checksum(frame) != frame[8]:
                return None
            dcm = struct.unpack_from("<H", frame, 2)[0]
            amp = struct.unpack_from("<H", frame, 4)[0]
            temp = struct.unpack_from("<H", frame, 6)[0] / 8.0 - 256.0
            valid = 100 <= amp <= 65_000
            return {
                "sensor": "tf_luna",
                "timestamp": time.time(),
                "distance_cm": dcm if valid else None,
                "distance_m": dcm / 100.0 if valid else None,
                "amplitude": amp,
                "chip_temp_c": round(temp, 1),
                "valid": valid,
            }
        except Exception as e:
            print(f"TF-Luna read error: {e}")
            return None
    def disconnect(self):
        if self._serial and self._serial.is_open:
            self._serial.close()
        self._connected = False
class SensorManager:
    def __init__(self, d500_port, tf_luna_port):
        self.d500 = LDRobotD500(port=d500_port)
        self.tf_luna = TFLuna(port=tf_luna_port)
    def initialize(self):
        return {"d500": self.d500.connect(), "tf_luna": self.tf_luna.connect()}
    def read_lidar(self):
        return self.d500.read_scan()
    def read_tf_luna(self):
        return self.tf_luna.read_distance()
    def read_all(self):
        return {"lidar_360": self.read_lidar(), "lidar_front": self.read_tf_luna(), "timestamp": time.time()}
    def shutdown(self):
        self.d500.disconnect()
        self.tf_luna.disconnect()

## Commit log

2026-03-31 Added 3d models to repository
    Added completed 3d models to the repository, they include main frame, electronics shelf, water resistant cover, landing gear and everything combined in one file.
    [Electronics shelf.step, Landing gear.step, Main frame.step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]
2026-03-31 Added BOM
    Added the Bill of materials as per the format.
    Note: Some items may be out of stock since as this is the end of the month, their stocks usually deplete. They usually restock within 1-2 weeks. Since we are in India, we are reliant on only a few su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
    [BOM.csv]
2026-04-30 changes to BOM
    [BOM.csv]
2026-05-04 wiring diagram update
2026-05-04 readme upd
    Updated wiring diagram image reference in README.
2026-05-04 Rename Wiring Diagram.png to Wiring-Diagram.png
2026-06-03 Final BOM Updates
2026-06-03 Update PCB section to include GPS and PCB 3
2026-06-09 cleaned up repo
    [Combination.3mf.stl, Dropper payload.3mf.stl, GPS.kicad_pcb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]
2026-06-11 Cleaned repository
    [Positions.csv]
2026-06-11 added step files
    [Battery+holder.stp, Cooling+system.stp, Electronics+shelf.stp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]
2026-06-28 add BOM
    [bom.csv]
2026-06-28 added assembly
2026-08-16 Gps update
    [GPS.kicad_pcb, GPS.kicad_sch, GPS_bom.csv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]
2026-08-19 Payload update
    [Payload_PCB.csv, Payload_PCB.kicad_pcb, Payload_PCB.kicad_sch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]
2026-08-19 FC update
    [HermesFC.csv, HermesFC.kicad_pcb, HermesFC.kicad_sch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]
